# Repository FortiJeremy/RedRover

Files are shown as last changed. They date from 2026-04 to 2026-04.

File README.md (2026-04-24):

# RedRover

A Curiosity/Perseverance-inspired rover built on the [Mars-Rover](https://github.com/jakkra/Mars-Rover)
mechanical and ESP32 firmware platform, extended with:

- **ArduRover** autopilot (Pixhawk / Matek / CubePilot) for full autonomous navigation
- **GPS + compass** for waypoint missions, RTL, and geo-fencing
- **LiDAR** (RPLidar A1 / TFMini-Plus) for proximity-based collision avoidance
- **SiK telemetry** radio link to Mission Planner / QGroundControl
- Refactored ESP32 firmware bridging MAVLink for arm, head, and auxiliary servo control

## Repo structure

```
RedRover/
  Mars-Rover/           ← git submodule — fork of jakkra/Mars-Rover (ESP32 firmware + CAD)
  3d-prints/            ← STL files exported from the Fusion 360 full assembly
    _context_only/      ← reference-only meshes (bearings, servos, motors, fasteners) — DO NOT PRINT
    01_chassis_body/    ← outer hull panels + electronics bay lid
    02_head_pack1/      ← head rotator, housing, camera mount, servo horns
    03_head_pack2/      ← large head top connector parts
    04_arm_structure/   ← arm links 1–3 and body connectors
    05_arm_gripper_connector/  ← gripper connector, rotator, printed servo horns
    06_gripper_fingers/ ← gear horns, finger arms, plates, rods
    07_suspension_connectors/  ← rocker-bogie pivot connectors (left + right)
    08_wheel_hub_smalls/ ← hub faces, axle flanges, steering knuckle small bodies
    09_wheel_corner_A/  ← corner wheel outer shell (×4)
    10_wheel_corner_B/  ← corner wheel inner shell / TPU candidate (×4)
    11_wheel_middle_A/  ← middle wheel outer skin / TPU candidate (×2)
    12_wheel_middle_B/  ← middle wheel inner body (×2)
    13_core_structure_A/ ← rover core body parts — large singles
    14_core_structure_B/ ← rover core body parts — batch B
    15_core_structure_C/ ← rover core body parts — batch C
    16_core_structure_D/ ← rover core body parts — batch D
    17_core_structure_E/ ← rover core body parts — batch E (includes Body46 ⚠️ verify before printing)
  ardurover/
    params/             ← ArduRover .param files
    docs/               ← calibration and setup guides
  docs/
    10_bom.md              ← full bill of materials (original + RedRover additions)
    20_print-settings.md   ← slicer settings and material guide per pack
    30_assembly.md         ← chapter-by-chapter assembly guide
    40_wiring.md           ← pin assignments, servo channel map, power rail overview
    50_ardurover-setup.md  ← ArduRover parameter setup, calibration, LiDAR, geofence
    60_gcs-setup.md        ← Mission Planner / QGC connection and field checklist
    70_firmware-esp32.md   ← ESP32 firmware architecture and MAVLink refactor plan
  TODO.md
  README.md
```

### 3D prints overview

295 STL files were exported from the Fusion 360 assembly. **156 files** are purchased-part
reference geometry (Ball Bearing 608ZZ, SKF 6005, Servo MG996R bodies, DC motors, McMaster
fasteners, Pololu hub) — these live in `_context_only/` and should **never** be sliced.
The remaining **139 files** are printable parts, organized into 17 build packs each under 10 MB
raw (slicer project files add overhead on top of the STL sizes).

> **Note on servo horns:** the `servo_and_horn v2 (N)_1_Body1.stl` files are the 3D-printed
> servo horns — they are in the build packs, not `_context_only/`, even though their sibling
> `Servo MG996R v2_*_Body*.stl` files are context-only.

See [TODO.md — Priority 5](TODO.md) for the full step-by-step organization plan and remaining tasks.

## Getting started

Clone with submodules:

```bash
git clone --recurse-submodules git@github.com:FortiJeremy/RedRover.git
```

If you already cloned without `--recurse-submodules`:

```bash
git submodule update --init --recursive
```

## Related repos

| Repo | Purpose |
|---|---|
| [FortiJeremy/Mars-Rover](https://github.com/FortiJeremy/Mars-Rover) | ESP32 peripheral firmware + Fusion 360 CAD (submodule) |
| [jakkra/Mars-Rover](https://github.com/jakkra/Mars-Rover) | Upstream source |
| [jakkra/RoverController](https://github.com/jakkra/RoverController) | Original handheld controller |

## Build status

Early build phase — see [TODO.md](TODO.md) for full scope.

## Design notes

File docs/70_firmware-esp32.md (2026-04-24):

# ESP32 Firmware

The ESP32 firmware lives in `Mars-Rover/src/` and is built with PlatformIO
targeting the **TTGO LoRa32 v1** (Espressif ESP32, Arduino framework).

---

## Current Architecture (upstream Mars-Rover)

The firmware runs on a single ESP32 and is the sole controller for the entire rover.
It handles RC input, WiFi/LoRa control, motor driving, servo control, IMU, and telemetry.

### Module overview

| File | Responsibility |
|---|---|
| `main.cpp` | Setup, main loop, mode switching, controller arbitration |
| `rover_config.h` | All pin assignments, RC ranges, servo trim offsets, constants |
| `rover_driving.cpp/.h` | ESC PWM output (left/right), steering servo, drive modes |
| `rover_servo.cpp/.h` | PCA9685 I2C servo driver — all 13 servo channels |
| `arm.cpp/.h` | 6-DOF arm axis movement with speed ramping (uses `Ramp` library) |
| `rover_head.cpp/.h` | Head yaw/pitch servo control |
| `rc_receiver_rmt.cpp/.h` | 6-channel RC PWM input via ESP32 RMT peripheral |
| `wifi_controller.cpp/.h` | Async WebSocket server + UDP; AP or STA mode |
| `lora_controller.cpp/.h` | LoRa radio TX/RX via arduino-LoRa library |
| `gyro_accel_sensor.cpp/.h` | MPU-6050 I2C IMU — reads accel/gyro/angle, runs in FreeRTOS task |
| `rover_settings_switch.cpp/.h` | Reads 2-position GPIO switches at boot to select startup mode |
| `switch_checker.cpp/.h` | RoverMode / ArmMode enum and debounce logic |
| `data/index.html` | Web UI (virtual joystick) — uploaded to SPIFFS via `pio run -t uploadfs` |
| `data/virtualjoystick.js` | Joystick library for web UI |

### Control arbitration

Three input sources compete for control. Priority order (highest wins):
1. **WiFi WebSocket** — overrides RC and LoRa when a client connects
2. **LoRa** — overrides RC when LoRa packets received and WiFi not connected
3. **RC receiver** — default fallback

### Drive modes (RoverMode)

Controlled by RC CH5 switch position:
- `DRIVE_TURN_NORMAL` — both ESCs same signal; corner servos steer normally
- `DRIVE_TURN_SPIN` — left/right ESCs run opposite directions for pivot turn

### Arm modes (ArmMode)

Controlled by RC CH6 switch position:
- `ARM_MODE_MOVE` — joysticks drive arm axes 1–4 (CH1–CH4)
- `ARM_MODE_MOVE_GRIPPER` — joysticks drive axes 5–6 (gripper)
- Direct axis control — no IK. **IK is listed as TODO in the original codebase.**

### Key constants (rover_config.h)

```c
RC_LOW    = 1000   // µs
RC_CENTER = 1500   // µs
RC_HIGH   = 2000   // µs
RC_FILTER_SAMPLES = 2          // sliding average filter window

SERVOMIN      = 250            // PCA9685 counts (normal range)
SERVOMAX      = 500
SERVOMIN_FULL_RANGE = 150      // extended range
SERVOMAX_FULL_RANGE = 600

SERVO_FRONT_LEFT_OFFSET  = +20
SERVO_FRONT_RIGHT_OFFSET = -15
SERVO_BACK_LEFT_OFFSET   = +5
SERVO_BACK_RIGHT_OFFSET  = -25
```

### Libraries (platformio.ini)

```ini
lib_deps =
    ESP32Servo           ; ESC and direct servo PWM
    Ramp                 ; Smooth servo speed ramping in arm.cpp
    MPU6050_tockn        ; MPU-6050 IMU driver
    Adafruit PWM Servo Driver Library  ; PCA9685 I2C servo expander
    AsyncTCP             ; Required by ESP Async WebServer
    ESP Async WebServer  ; WebSocket + HTTP server for web UI
    arduino-LoRa (sandeepmistry)  ; LoRa radio
```

---

## RedRover Refactor Plan

The ESP32 is demoted from sole controller to peripheral/companion.
ArduRover FC handles all motor/ESC control and navigation; ESP32 manages
servos (arm, head, steering) and acts as a MAVLink bridge.

### Changes required

#### 1. Remove direct ESC control
- `rover_driving.cpp`: disable/stub out `motors_left` and `motors_right` ESC PWM output
- GPIO 17 and 13 no longer used for ESC signal
- `rover_driving_move()` to be replaced with MAVLink RC override or removed entirely

#### 2. Remove direct RC receiver input for motion
- RC receiver SBUS/PPM physically rewired to FC RC IN port
- The 6 RC GPIO inputs (34, 35, 4, 39, 25, 36) may be repurposed or left as monitoring-only
- Arm and head RC channels can still be read locally on ESP32, or forwarded via MAVLink

#### 3. Add MAVLink serial link to FC
- New UART on ESP32 (e.g. `Serial2`) connected to FC TELEM2 port
- Add `mavlink` library to `platformio.ini`
- Implement heartbeat TX (Type: `MAV_TYPE_ONBOARD_CONTROLLER`)
- Parse incoming heartbeat + `RC_CHANNELS_OVERRIDE` from FC

#### 4. Retain servo control
- PCA9685 I2C bus and all 13 servo channels remain on ESP32
- `rover_servo.cpp` unchanged — still drives arm (axes 1–6), steering (4 corners), head (yaw + pitch)
- Arm mode / head control still driven by WiFi WebSocket or LoRa

#### 5. Telemetry bridge (optional)
- ESP32 reads MAVLink telemetry from FC (battery, GPS, mode, heading)
- Forwards over WebSocket to browser or custom GCS web UI
- Existing `wifi_controller.cpp` WebSocket infrastructure can be reused

#### 6. Arm IK (future)
- `arm.cpp` currently maps RC channels 1:1 to axis µs positions
- Plan: implement FABRIK or analytical 6-DOF IK
- IK target (x,y,z + euler) accepted via WebSocket JSON message or MAVLink custom message
- `arm_move()` already has speed parameter — reuse for IK interpolation

---

## Build & Flash

```bash
# Build
pio run

# Flash
pio run -t upload

# Monitor serial
pio device monitor

# Upload web UI to SPIFFS
pio run -t uploadfs

# Decode crash stack trace
xtensa-esp32-elf/bin/xtensa-esp32-elf-addr2line.exe -pfiaC -e .pio/build/esp-wrover-kit/firmware.elf 0x...
```

Default port: `COM8` at 921600 baud upload / 115200 baud monitor (set in `platformio.ini`).
Update `upload_port` / `monitor_port` in `platformio.ini` if your port differs.

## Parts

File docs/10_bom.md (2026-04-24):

# Bill of Materials

---

## Original Mars-Rover Hardware

These are the parts from the upstream jakkra/Mars-Rover design.
Quantities are for the full rover with arm and head.

### Drive System

| Part | Qty | Notes |
|---|---|---|
| 12V 60RPM DC motor | 6 | One per wheel — see [issue #6](https://github.com/jakkra/Mars-Rover/issues/6) for specific model |
| Brushless ESC | 2 | One per side (each drives 3 motors in parallel) |
| Pololu 4mm shaft hub (M3 holes) | 6 | [Pololu #1081](https://www.pololu.com/product/1081) — motor-to-wheel adapter |

### Steering & Servos

| Part | Qty | Notes |
|---|---|---|
| MG946R or MG996R servo | 4 | Corner wheel steering |
| MG946R servo | 6 | 6-DOF arm axes |
| MG946R or MG996R servo | 2 | Head yaw + pitch |
| Round Metal Servo Horn 25T Disc | 12 | One per servo — check spline compatibility |

### Power

| Part | Qty | Notes |
|---|---|---|
| 3S LiPo battery | 1 | Capacity TBD based on runtime target — suggest 5000–6000 mAh |
| 12V → 5V switching voltage regulator | 12 | One per servo — can be replaced with high-current BECs (see RedRover additions) |

### Compute & Control

| Part | Qty | Notes |
|---|---|---|
| TTGO LoRa32 v1 (ESP32) | 1 | Main MCU — board used in platformio.ini |
| Adafruit PCA9685 PWM servo driver | 1 | I2C servo expander — drives all 13 servos on channels 0–12 |
| MPU-6050 IMU (gyro/accel) | 1 | On I2C bus with PCA9685 |
| 6-channel RC receiver | 1 | Generic PPM/PWM receiver |
| LoRa radio module | 1 | Built into TTGO LoRa32 (SX1276 or SX1278) |

### Structural

| Part | Qty | Notes |
|---|---|---|
| PVC pipe, ID 23.40 mm / OD 25 mm | TBD | Rocker-bogie arms — measure from CAD |
| Ball bearing 608ZZ | 5+ | Check CAD for exact count per side |
| Bearing SKF 6005 (25 mm) | 5+ | Larger wheel pivot bearings — check CAD |
| M3 screws assorted | ~100 | Primary fastener throughout |
| M4 screws assorted | ~20 | Larger structural joints |
| M3 heat-set inserts | ~50 | For 3D-printed holes — strongly recommended over direct screw-in |

---

## RedRover Additions (ArduRover / GPS / LiDAR build)

### Autopilot

| Part | Qty | Notes |
|---|---|---|
| ArduRover-compatible flight controller | 1 | **Recommended:** Pixhawk 6C, Matek H743-Wing, or CubePilot Orange+ |
| Vibration isolation foam / mounting kit | 1 | Required under FC — standard FC mounting foam |

### Navigation

| Part | Qty | Notes |
|---|---|---|
| u-blox M8N or M9N GPS + compass module | 1 | **Recommended:** Here3 or mRo GPS — integrated compass |
| GPS mast (printed or purchased) | 1 | Elevates GPS above chassis electronics noise |

### Collision Avoidance

| Part | Qty | Notes |
|---|---|---|
| RPLidar A1M8 (360° 2D LiDAR) | 1 | **Recommended** — full perimeter coverage, ~$100, supported natively by ArduRover `PRX_TYPE=5` |
| *OR* TFMini-Plus (single-point ToF) | 1 | Budget alternative — forward-only, `RNGFND1_TYPE=20` |

### Telemetry

| Part | Qty | Notes |
|---|---|---|
| SiK 915 MHz radio pair | 1 pair | e.g. RFD900x or HolyBro SiK v3 — one on rover, one to GCS |

### Power

| Part | Qty | Notes |
|---|---|---|
| ArduRover power module | 1 | e.g. **Matek HUBOSD** or Holybro PM02 — provides VBAT + current sense to FC ADC |
| 5A BEC (12V → 5V) | 2–3 | e.g. Matek MBEC6S — replaces 12× individual regulators. One per servo rail zone |
| Power distribution board (PDB) | 1 | Routes 12V from battery to ESCs, BECs, FC, LiDAR |
| 30–40A blade fuse + holder | 1 | Main fuse between battery and PDB |
| XT60 connector pair | 2–3 | Battery and PDB connections |

### Safety

| Part | Qty | Notes |
|---|---|---|
| ArduRover safety arming button | 1 | Wired to FC safety switch port — required for arming |

---

## Connectors & Wiring Hardware

| Part | Notes |
|---|---|
| JST connectors assorted | ESC signal, servo extensions |
| Dupont 2.54mm header kit | ESP32 and FC GPIO breakouts |
| Heat-shrink tubing assorted | |
| Cable ties / wire loom | |
| XT30 or XT60 pigtails | ESC power inputs |

---

## Still TBD

- [ ] Exact DC motor model/SKU — see Mars-Rover issue #6
- [ ] Cable loom lengths — measure from CAD / physical assembly
- [ ] ESC model selection — confirm PWM range compatible with ArduRover output
- [ ] 3S LiPo C-rating and capacity — size to current budget once calculated
- [ ] Heat-set insert sizes per part — note during assembly

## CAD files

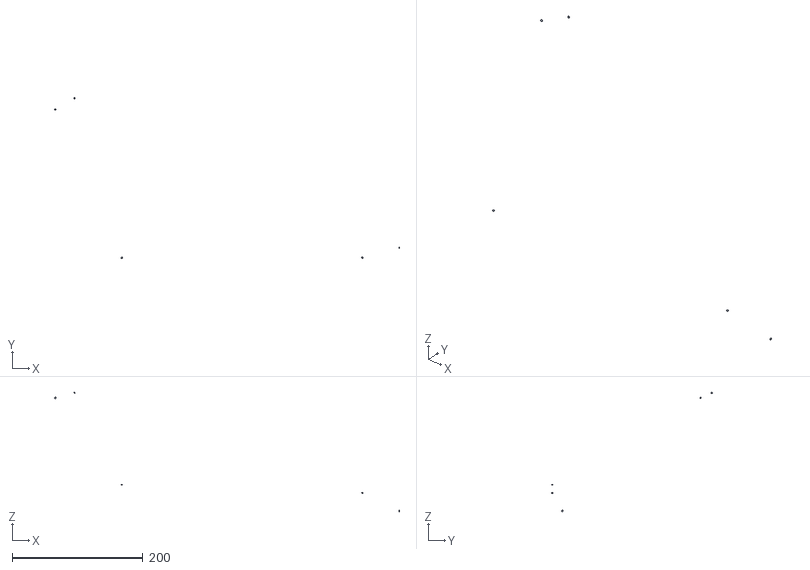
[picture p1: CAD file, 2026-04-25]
3d-prints/_context_only/Rover_Full_Rover_Full_Rover body_1_Rover core and arm v81_1_arm_gripper_connector_1_servo_and_horn v2 (2)_1_Servo MG996R v2_3_Body4.stl
528.2 x 247.0 x 183.1

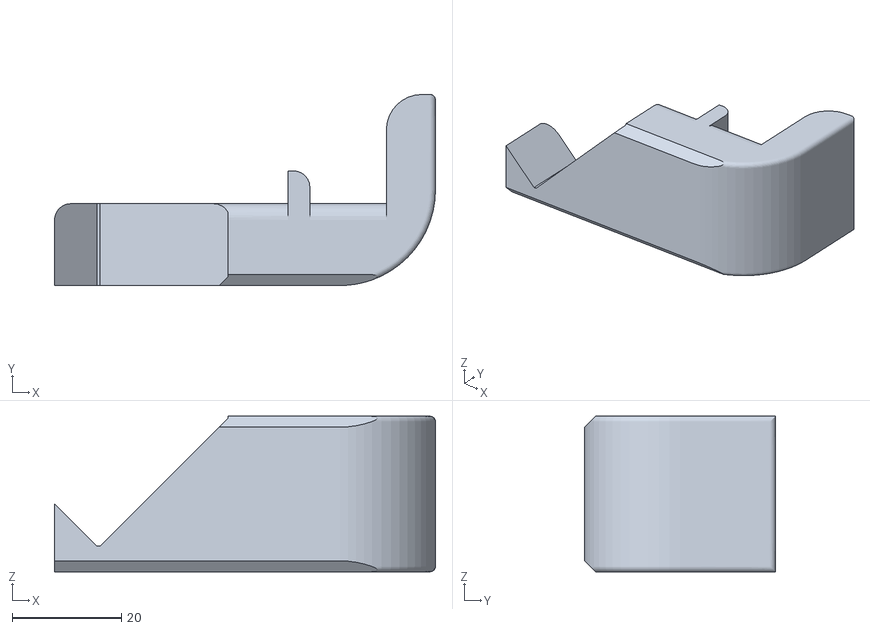
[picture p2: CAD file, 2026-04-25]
3d-prints/arm_objects/Rover_Full_Rover_Full_arm_holder_1_Body1.stl
69.8 x 35.0 x 28.5

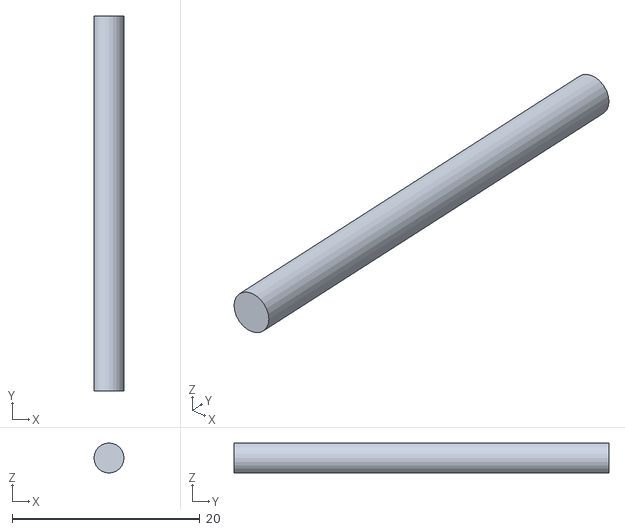
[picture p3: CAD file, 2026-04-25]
3d-prints/back_antennae/Rover_Full_Rover_Full_ruhf_antenna_1_Body6.stl
3.20 x 40.0 x 3.20

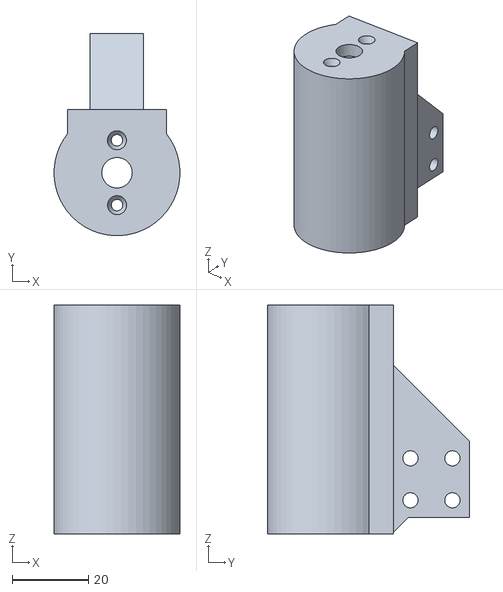
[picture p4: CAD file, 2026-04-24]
3d-prints/Body/1-middle-wheels/Rover_Full_Rover_Full_Rover body_1_Rover core and arm v81_1_Rover core v232_1_middle_wheel_1_Body1.stl
32.9 x 53.0 x 60.0

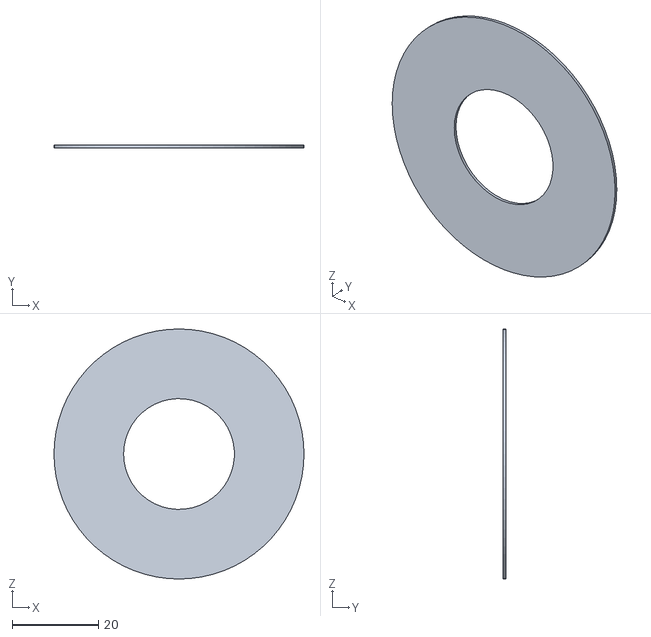
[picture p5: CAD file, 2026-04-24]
3d-prints/Body/1-port-driveline/Rover_Full_Rover_Full_Rover body_1_Rover core and arm v81_1_Rover core v232_1_Body35.stl
58.0 x 0.6 x 58.0

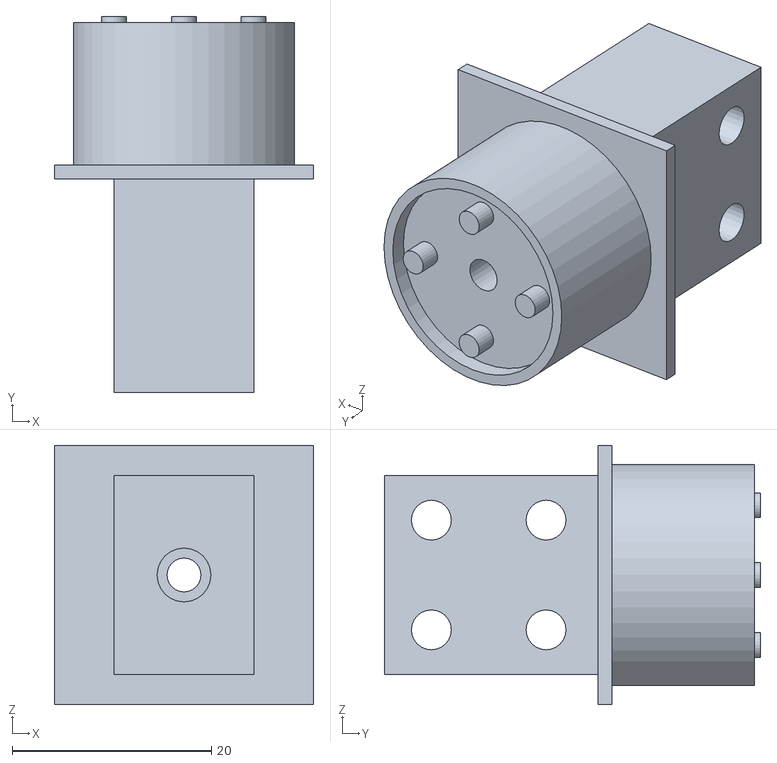
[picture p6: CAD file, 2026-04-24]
3d-prints/Body/1-starboard-driveline/Rover_Full_Rover_Full_Rover body_1_Rover core and arm v81_1_Rover core v232_1_Body1.stl
26.0 x 37.7 x 26.0

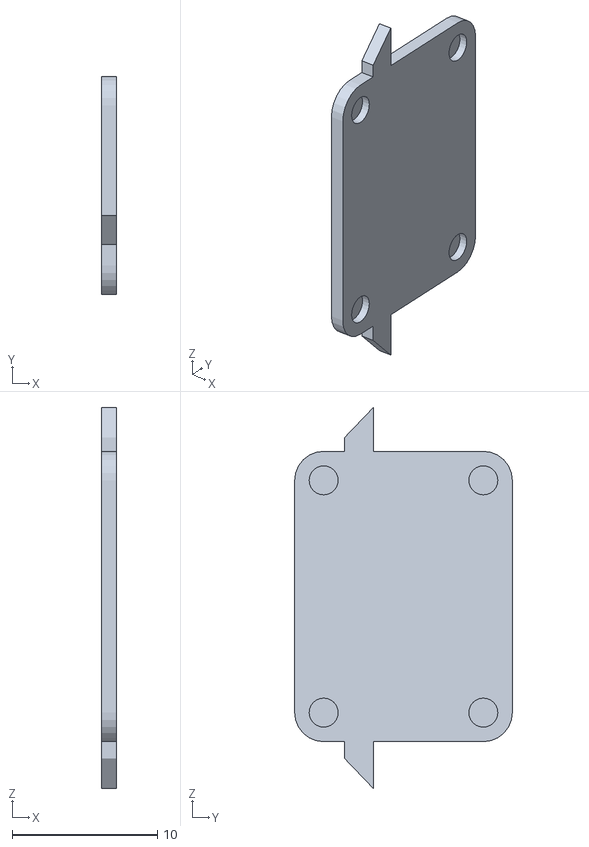
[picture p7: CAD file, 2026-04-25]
3d-prints/Body/main-box/_context_only/Rover_Full_Rover_Full_Rover body_1_Body9.stl
1.00 x 15.0 x 26.2

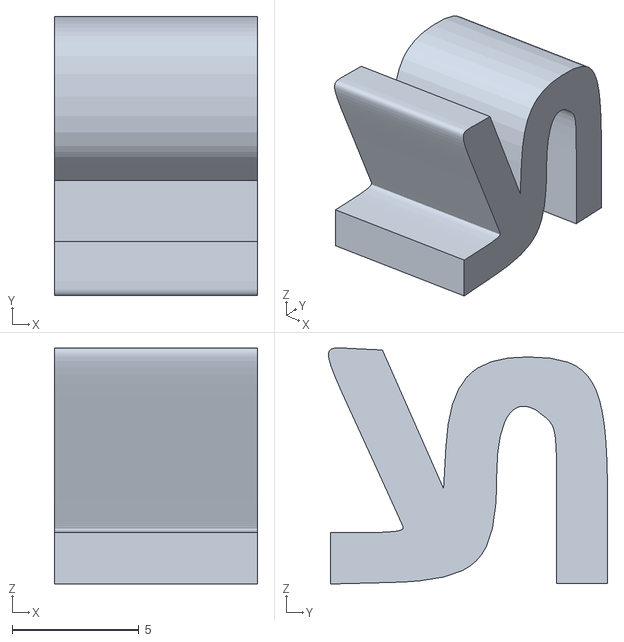
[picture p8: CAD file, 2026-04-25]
3d-prints/Body/main-box/Krantz-Logo-Back/Rover_Full_Rover_Full_Rover body_1_Rover core and arm v81_1_Rover core v232_1_Body48.stl
8.00 x 11.0 x 9.30

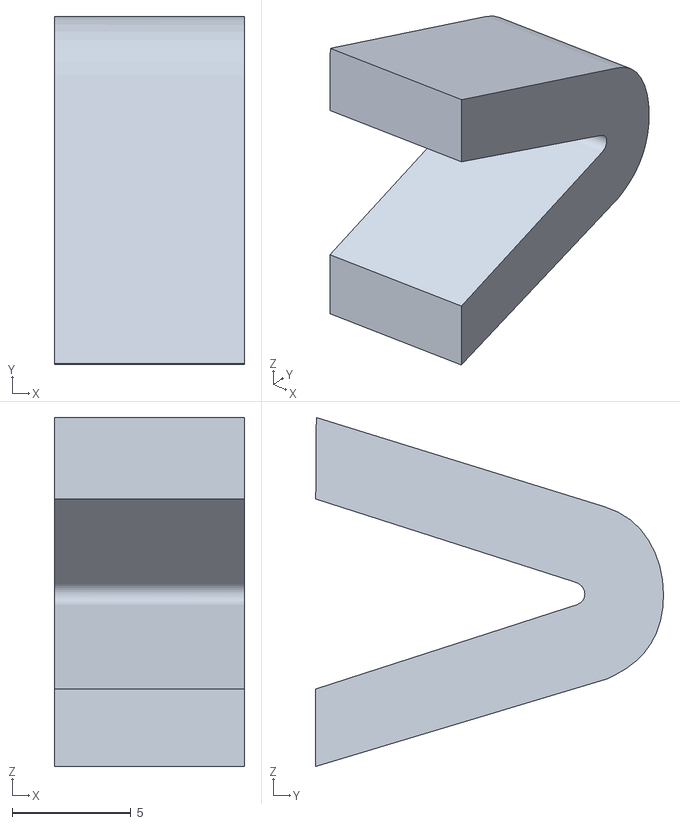
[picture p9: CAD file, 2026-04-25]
3d-prints/Body/main-box/NASA-Logo-Front/Rover_Full_Rover_Full_Rover body_1_Rover core and arm v81_1_Rover core v232_1_Body43.stl
8.00 x 14.6 x 14.7

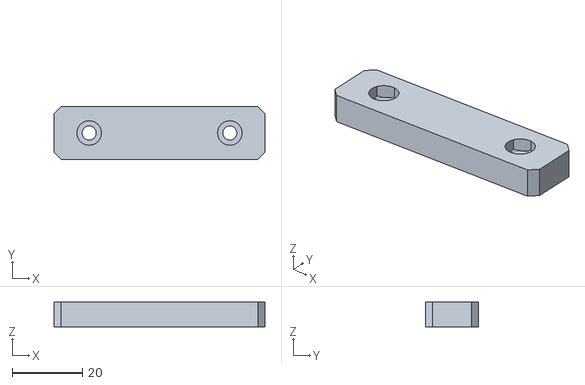
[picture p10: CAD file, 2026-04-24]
3d-prints/Body/main-box/Rover_Full_Rover_Full_Rover body_1_Rover core and arm v81_1_Rover core v232_1_Body40.stl
60.0 x 15.0 x 7.00

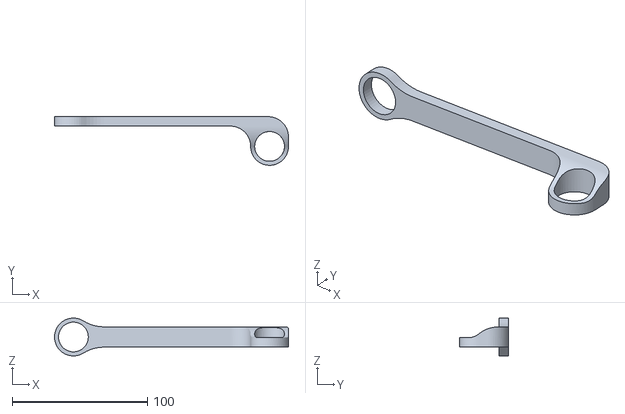
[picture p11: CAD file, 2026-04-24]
3d-prints/Body/sway-link/Rover_Full_Rover_Full_Rover body_1_Rover core and arm v81_1_Rover core v232_1_Body22.stl
173.0 x 36.0 x 28.0

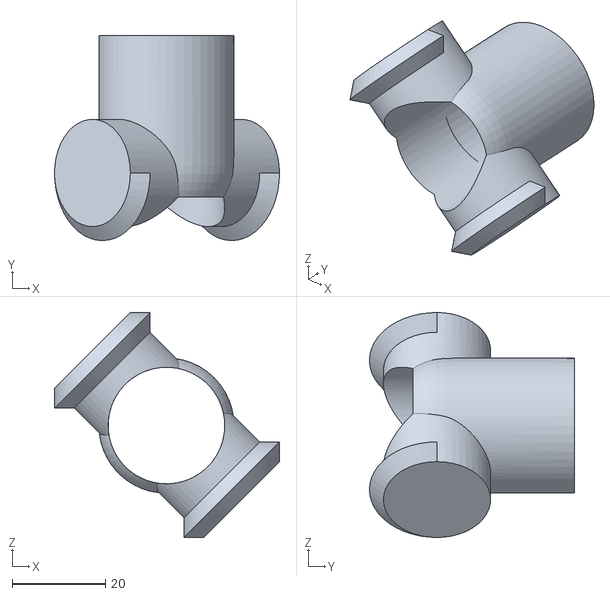
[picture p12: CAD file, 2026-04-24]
3d-prints/camera/Rover_Full_Rover_Full_Rover body_1_head_top_connector_1_Body3.stl
48.2 x 44.0 x 48.2

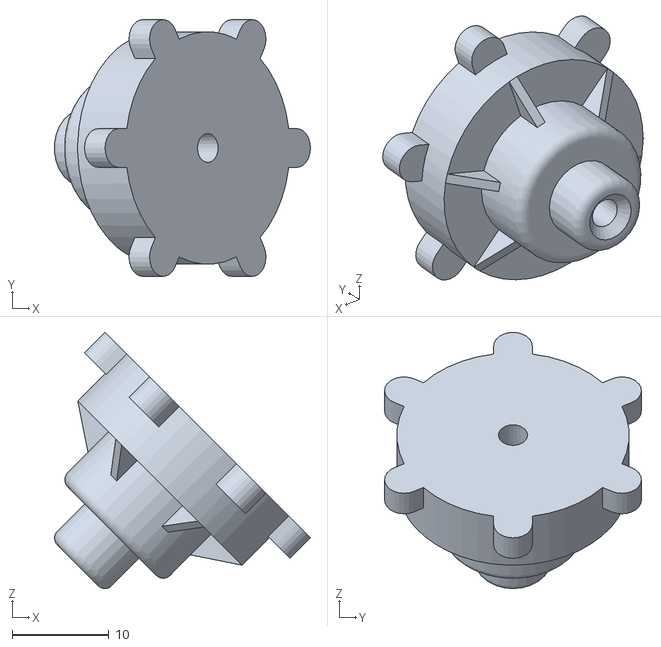
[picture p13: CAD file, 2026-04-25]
3d-prints/large_antenna/Rover_Full_Rover_Full_large_antenna_1_Body17.stl
26.4 x 26.5 x 26.5

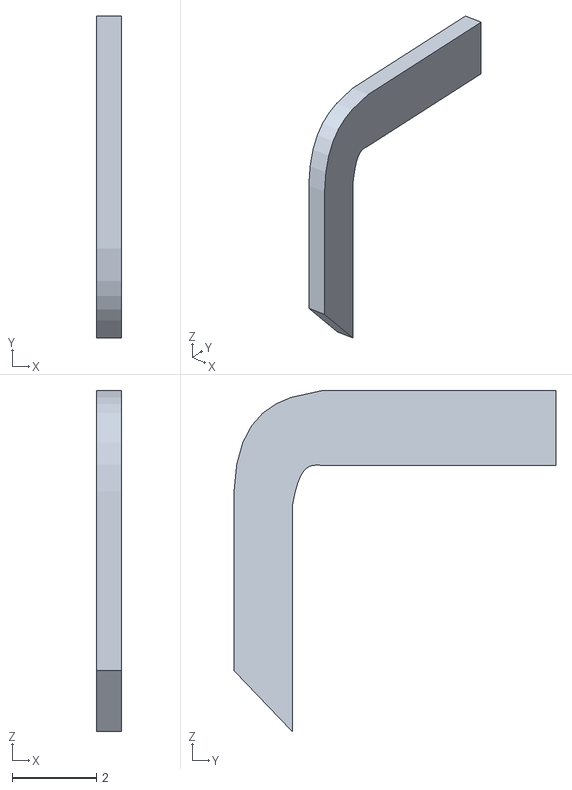
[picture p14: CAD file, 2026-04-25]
3d-prints/Reactor_and_addons/Rover_Full_Rover_Full_Body5.stl
0.6 x 7.64 x 8.11

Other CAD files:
3d-prints/Body/1-rear-corner-wheels/Rover_Full_Rover_Full_Rover body_1_Rover core and arm v81_1_Rover core v232_1_corner_wheel2_1_Body3.stl
3d-prints/Top_Thingies/Rover_Full_Rover_Full_top_thingy(Mirror)_1_Body2.stl
3d-prints/3mf-files/MainBox.3mf
3d-prints/_context_only/Rover_Full_Rover_Full_large_antenna_1_servo_and_horn v2 (1) (1)_1_Servo MG996R v2 (1)_1_Body3.stl
3d-prints/3mf-files/Lids&Side.3mf
3d-prints/Body/1-middle-wheels/Rover_Full_Rover_Full_Rover body_1_Rover core and arm v81_1_Rover core v232_1_middle_wheel_1_Body2.stl
3d-prints/Body/1-middle-wheels/Rover_Full_Rover_Full_Rover body_1_Rover core and arm v81_1_Rover core v232_1_middle_wheel_1_Body5.stl
3d-prints/Body/1-port-driveline/Rover_Full_Rover_Full_Rover body_1_Rover core and arm v81_1_Rover core v232_1_Body27.stl
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

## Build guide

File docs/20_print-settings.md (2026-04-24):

# 3D Print Settings

Reference slicer settings and material recommendations for all RedRover printed parts.
Print packs are in `3d-prints/` — see the [repo README](../README.md) for the full pack list.

---

## Material Guide by Sub-Assembly

| Pack | Sub-assembly | Recommended material | Rationale |
|---|---|---|---|
| 01 | Chassis body panels | PETG or PLA+ | Light structural load, cosmetic accuracy matters |
| 02–03 | Head assembly | PLA+ | Low stress, dimensional accuracy for servo fits |
| 04–05 | Arm structure + gripper connector | PETG | Repeated torsional loads on arm links |
| 06 | Gripper fingers / gear horns | PETG | Wear surface on gear teeth |
| 07 | Suspension connectors (rocker-bogie) | PETG or ASA | High stress pivot joints — do NOT use PLA |
| 08 | Wheel hub small parts | PETG | Axle loads |
| 09, 11 | Wheel outer skins | **TPU 95A** (flex) or PETG (rigid) | TPU gives Mars 2020-style grip on outdoor terrain |
| 10, 12 | Wheel inner shells | PETG | Structural backbone of wheel |
| 13–17 | Rover core structure | PETG | Frame members carry most structural load |

---

## General Slicer Settings (starting point — tune per printer)

| Parameter | Value | Notes |
|---|---|---|
| Layer height | 0.2 mm | 0.15 mm for servo horn mating surfaces |
| Line width | 0.4 mm (nozzle) | |
| Infill — structural parts | 40% gyroid | Rocker-bogie pivots, arm links, wheel hubs |
| Infill — cosmetic/light parts | 20% gyroid | Panels, head housing |
| Perimeters / walls | 4 | Minimum for all structural parts |
| Top/bottom layers | 5 | |
| Print speed | 50 mm/s | Slow to 30 mm/s for first layer and bridges |
| Supports | See per-pack notes | Use tree/organic supports where possible |
| Bed adhesion | Brim 5 mm | For tall narrow parts; raft for TPU |

---

## TPU-Specific Settings (wheel outer skins — packs 09 & 11)

| Parameter | Value |
|---|---|
| Print speed | 20–25 mm/s |
| Retraction | Disabled or ≤0.5 mm (direct drive) / Off (Bowden) |
| Temperature | ~230°C nozzle, ~45°C bed |
| Cooling fan | 100% after layer 3 |
| Infill | 15% gyroid — gives flex behaviour |
| Walls | 3 |
| Bed adhesion | PEI sheet or glue stick on glass |

---

## Pack-Specific Notes

### Pack 07 — Suspension Connectors
- `main_leg_body_connector` and its mirror are the single highest-stress printed parts.
  Orient so layer lines run along the length of the arm (perpendicular to the load).
- If using PETG, anneal in oven at 65°C for 2 hrs after printing for improved creep resistance.

### Pack 09 / 10 — Corner Wheels (×4 each)
- Body1 (~4 MB) is a large print — validate fit with a single copy before queuing all 4.
- Print corner wheel outer and inner as separate jobs; glue or snap together after.
- Wheel outer needs 4 copies; mirror is handled in hardware (symmetric wheel), not by mirroring the STL.

### Pack 11 / 12 — Middle Wheels (×2 each)
- Same approach as corner wheels — validate one before printing the second.

### Pack 13 — Core Structure Large Bodies
- Body6 and Body33 are each ~4 MB — likely main chassis frame rails. Verify print bed fits.
- Best orientation: flat face down, no supports on inner channels if hollowed.

### Pack 17 — Body46 ⚠️
- Body46 is 7.3 KB — very small mesh. Open in CAD before printing; may be a hardware reference
  that was not caught in the context-only pass.

---

## Print Order Recommendation

Print in this dependency order so you can begin dry-fitting before all parts are done:

1. Packs 13–17 (core structure) — longest print time, needed first for chassis assembly
2. Pack 07 (suspension connectors)
3. Pack 08 + 09 + 10 (wheel hubs + corner wheel shells) × 4
4. Pack 11 + 12 (middle wheel shells) × 2
5. Pack 01 (chassis body panels)
6. Pack 04 + 05 + 06 (arm structure + gripper)
7. Packs 02 + 03 (head)

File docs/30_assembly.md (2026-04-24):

# Assembly Guide

High-level chapter guide for building the RedRover. Each section corresponds to a
physical sub-assembly. Follow the order below — each stage should be testable on its own
before moving to the next.

> **Reference:** Keep the Fusion 360 model open (`Mars-Rover/CAD/Rover_Full.f3d`) throughout.
> The CAD is the source of truth for all dimensions, orientations, and fit.

---

## Chapter 1 — Tools & Prep

**Required tools:**
- M3 and M4 hex keys (ball-end preferred)
- M3 / M4 screwdriver bits
- Soldering iron with fine tip
- Heat-set insert tip for soldering iron (M3 preferred)
- Needle-nose pliers
- Bearing press tool (or M3 bolt + nut + socket as improvised press)
- Digital calipers
- Hot glue gun (cable management / light tacks only — no structural glue)

**Before starting:**
- [ ] Install all heat-set inserts into printed parts before assembly — much easier to do on the bench
- [ ] Test-fit all bearings dry before pressing — 608ZZ into wheel hubs, SKF 6005 into pivot journals
- [ ] Ream any tight bearing seats with a hobby knife or light sandpaper — do not force-press into undersized holes
- [ ] Sand/file any layer lines on servo mounting faces to ensure servo horns seat flush

---

## Chapter 2 — Rocker-Bogie Suspension

The rocker-bogie is the structural spine of the rover. Six wheels are driven by a passive
differential linkage; the front and rear corners steer independently.

**Main printed parts (from print packs 07, 13–17):**
- 2× `main_leg_body_connector` (left + right)
- 2× `back_two_wheel_connector` (left + right)
- Rover core frame bodies from packs 13–17

**Purchased hardware:**
- PVC pipe (ID 23.40 mm / OD 25 mm) — cut to lengths from CAD
- SKF 6005 25 mm bearings (pivot journals)
- 608ZZ bearings (wheel axles)
- M3 / M4 fasteners and heat-set inserts

**Assembly steps (TBD — cross-reference CAD):**
- [ ] Assemble left and right bogie links with PVC pipe inserts
- [ ] Press SKF 6005 bearings into pivot housings (main_leg_body_connector)
- [ ] Connect rocker to bogie via pivot pin — confirm free rotation, no binding
- [ ] Attach bogie sub-assemblies to core frame rails
- [ ] Install differential rocker bar between left and right bogies

**Alignment check:**
- With rover on a flat surface, all 6 wheel contact points should touch simultaneously
- Rocker pivot should float freely — it should not be fastened rigidly

---

## Chapter 3 — Drive Train

Each of the 6 wheels is independently driven by a 12V 60RPM DC motor.
Motors on the left 3 wheels share one ESC; right 3 wheels share the second ESC.

**Main printed parts (from packs 08, 09, 10, 11, 12):**
- 4× corner wheel assembly (outer + inner shell, hub small parts)
- 2× middle wheel assembly (outer + inner shell)

**Purchased hardware:**
- 6× DC motor
- 6× Pololu #1081 shaft hub
- 608ZZ bearings
- M3 fasteners

**Assembly steps (TBD):**
- [ ] Mount each DC motor into its wheel housing
- [ ] Press Pololu shaft hubs onto motor 4mm output shaft — secure M3 grub screws with Loctite
- [ ] Press 608ZZ bearings into outer wheel shells
- [ ] Assemble wheel outer shell onto hub — verify correct side (asymmetric for cornering)
- [ ] Mount wheel assemblies to bogie arms — check for wheel toe/camber

**Corner wheel note:**
Corner wheels carry a steering servo in addition to the drive motor. See Chapter 4 for
steering servo installation before finalising corner wheel assembly.

---

## Chapter 4 — Steering Servos (Corner Wheels)

Four MG946R/MG996R servos steer the front-left, front-right, back-left, and back-right wheels.
Servos are installed inside the corner wheel assembly and driven via the PCA9685 expander.

**PCA9685 servo channels (from `rover_servo.h`):**
| Channel | Servo |
|---|---|
| 6 | `SERVO_FRONT_RIGHT` |
| 7 | `SERVO_BACK_LEFT` |
| 8 | `SERVO_FRONT_LEFT` |
| 9 | `SERVO_BACK_RIGHT` |

**Trim offsets (from `rover_config.h`):**
| Servo | Offset |
|---|---|
| Front Left | +20 µs |
| Front Right | −15 µs |
| Back Left | +5 µs |
| Back Right | −25 µs |

**Assembly steps (TBD):**
- [ ] Install servo into corner wheel housing — align spline notch before inserting
- [ ] Attach 25T disc horn — set to mechanical centre first using servo tester or firmware
- [ ] Verify wheel points straight ahead at 1500 µs centre signal
- [ ] Fine-tune offsets in `rover_config.h` if required

---

## Chapter 5 — 6-DOF Arm

The arm has 6 servo-driven joints (MG946R). Currently the arm is directly RC-mapped;
inverse kinematics is planned for a future firmware update.

**Main printed parts (from packs 04, 05, 06):**
- arm link 1 (`arm_1_1_Body1`)
- arm body connector (`arm_body_connector_1_Body1`)
- arm links 2 + mirror (`arm2`, `arm2(Mirror)(Mirror)`)
- arm link 3 (`arm3_1_Body1`)
- gripper connector assembly (`arm_gripper_connector_1_Body1/2`)
- grip rotator (`grip_rotator_1_Body1`)
- gripper finger assembly (packs 06)
- 3× printed servo horns (`servo_and_horn v2 (1–3)_1_Body1`)

**PCA9685 servo channels (from `rover_servo.h`):**
| Channel | Servo |
|---|---|
| 0 | `SERVO_ARM_AXIS_1` |
| 1 | `SERVO_ARM_AXIS_2` |
| 2 | `SERVO_ARM_AXIS_3` |
| 3 | `SERVO_ARM_AXIS_4` |
| 4 | `SERVO_ARM_AXIS_5` |
| 5 | `SERVO_ARM_AXIS_6` |

**Assembly steps (TBD):**
- [ ] Install AXIS_1 servo at base rotation joint (arm_body_connector)
- [ ] Route wiring through hollow arm links before closing
- [ ] Assemble links 1 → 2 → 3 in order — test each joint range before proceeding
- [ ] Install gripper connector and grip rotator (AXIS_5)
- [ ] Install gripper servo at AXIS_6 — connect gear horns
- [ ] Balance arm weight at each joint; note if any joint stalls under static load

**Arm range of motion:**
SERVOMIN (250) to SERVOMAX (500) in PCA9685 counts (full range: 150–600).
Firmware clamps to reduced range by default to protect servo gears.

---

## Chapter 6 — Head

The head has yaw (left/right) and pitch (up/down) driven by two MG946R/MG996R servos.
An ESP32-CAM mounts in the head for the video feed.

**Main printed parts (from packs 02, 03):**
- head rotator body (`head_rotator_1_Body1/2/3`)
- head housing (`head_rotator_1_head_1_Body1/2/3/4`)
- head top connector assembly (`head_top_connector_1_Body*`)
- ESP32-CAM holder (`espcam_holder_1_Body1/2`)
- 2× printed servo horns (`servo_and_horn v2 (4)_1_Body1`, `v2 (5)_1_Body1`)

**PCA9685 servo channels (from `rover_servo.h`):**
| Channel | Servo |
|---|---|
| 11 | `SERVO_HEAD_YAW` |
| 12 | `SERVO_HEAD_PITCH` |

**RC channel mapping (from `rover_config.h`):**
- Head yaw: RC_CH3 (GPIO4)
- Head pitch: RC_CH4 (GPIO39)

**Assembly steps (TBD):**
- [ ] Install yaw servo into head_rotator bracket; attach printed horn
- [ ] Install pitch servo into head housing; attach printed horn
- [ ] Mount ESP32-CAM into espcam_holder — confirm camera faces forward
- [ ] Mount head sub-assembly onto top of rover body via head_top_connector
- [ ] Verify full yaw/pitch range without cable binding

**Sensor mast note (RedRover addition):**
If mounting RPLidar on the head/top deck rather than a separate mast, provision cable path
and mount clearance for the LiDAR sensor here.

---

## Chapter 7 — Electronics Bay

The electronics bay is inside the main chassis body, covered by the printed lid (`Lid1.stl`).

**Planned component layout (TBD — diagram needed):**
- ArduRover flight controller (centre, vibration-isolated)
- TTGO LoRa32 ESP32 board
- PCA9685 PWM servo driver (I2C to ESP32)
- Power module (battery-side of PDB)
- PDB / BEC modules
- SiK telemetry radio
- RC receiver
- Safety arming button (mounted through lid or body panel)

**Assembly steps (TBD):**
- [ ] Mount PDB to bay floor — confirm cable routing to all 6 motors and servo BEC rails
- [ ] Mount power module in-line between XT60 battery connector and PDB
- [ ] Mount ArduRover FC on vibration foam — orient arrow forward
- [ ] Mount ESP32 (TTGO LoRa32) adjacent to FC — UART link between them
- [ ] Route all servo signal wires to PCA9685
- [ ] Route RC receiver to ESP32 GPIOs 34, 35, 4, 39, 25, 36 (CH1–CH6)
- [ ] Install safety button — wire to FC safety port
- [ ] Lid test fit — confirm no cables pinched

---

## Chapter 8 — First Power-On Checklist

Before first full power-on with all components connected:

- [ ] Verify polarity on all ESC power connections before plugging in
- [ ] Confirm all servo power rails are on regulated 5V, not direct battery
- [ ] Check for any short circuits across PDB rails with multimeter (no battery connected)
- [ ] Connect battery — check for smoke, heat, or excessive current draw before proceeding
- [ ] Verify FC boots and shows solid LED (no FC-specific error indications)
- [ ] Confirm ESP32 serial output on 115200 baud — check for crash/reboot loops
- [ ] Test each servo to centre before connecting to arm/steering linkages
- [ ] Test each motor direction — verify left/right ESC mapping matches firmware

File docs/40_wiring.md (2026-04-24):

# Wiring & Electrical

Wiring reference for the RedRover. The original Mars-Rover was a single-board ESP32 system;
the RedRover adds an ArduRover flight controller between the battery/ESCs and the ESP32,
which becomes a peripheral/companion board.

---

## System Architecture Overview

```
Battery (3S LiPo)
    │
    ├─ XT60 ──► Power Module ──► (VBAT + current sense to FC ADC)
    │                │
    │           PDB / Bus
    │           │          │          │          │
    │         ESC L       ESC R     BEC 1      BEC 2/3
    │       (Motors       (Motors   (5V servo  (5V for FC,
    │        L×3)          R×3)      rail)      ESP32, LiDAR)
    │
    └─ Fuse (30–40A blade)
```

---

## ESP32 (TTGO LoRa32 v1) Pin Assignment

From `src/rover_config.h`:

### RC Receiver Inputs (still wired direct to ESP32 in current firmware; to be rerouted to FC in RedRover)

| ESP32 GPIO | Signal | RC Channel |
|---|---|---|
| 34 | RC_CH1_INPUT | Steering |
| 35 | RC_CH2_INPUT | Throttle |
| 4 | RC_CH3_INPUT | Head Yaw |
| 39 | RC_CH4_INPUT | Head Pitch |
| 25 | RC_CH5_INPUT | Rover mode switch |
| 36 | RC_CH6_INPUT | Arm mode switch |

> **RedRover change:** RC receiver SBUS/PPM output will move to ArduRover FC RC IN port.
> ESP32 will receive RC channel values via MAVLink RC override messages from FC.

### Motor ESC Outputs (to be removed in RedRover — FC takes over)

| ESP32 GPIO | Signal |
|---|---|
| 17 | ESC left (3× motors) — PWM 1000–2000 µs |
| 13 | ESC right (3× motors) — PWM 1000–2000 µs |

> **RedRover change:** These pins will be disabled. ArduRover FC outputs drive both ESCs
> directly on its PWM output channels.

### I2C Bus

| ESP32 GPIO | Signal |
|---|---|
| 21 | SDA |
| 22 | SCL |

I2C devices on this bus:
- **PCA9685** PWM servo driver (13 servo channels — see servo channel table below)
- **MPU-6050** IMU (gyro/accel)

### Settings Switches (boot mode selection)

| ESP32 GPIO | Signal |
|---|---|
| 2 | ROVER_SETTINGS_SWITCH_1 |
| 23 | ROVER_SETTINGS_SWITCH_2 |

3-position switch combination controls startup mode:
- `ROVER_SWITCH_STATE_STATION_LORA` → WiFi station + LoRa enabled
- `ROVER_SWITCH_STATE_AP` → WiFi AP mode (hosted web UI)
- `ROVER_SWITCH_STATE_LORA_ONLY` → LoRa only, no WiFi

---

## PCA9685 Servo Driver Channel Map

All servos are driven through a single PCA9685 I2C PWM expander.
From `src/rover_servo.h`:

| PCA9685 Channel | RoverServoId | Connected servo |
|---|---|---|
| 0 | `SERVO_ARM_AXIS_1` | Arm base rotation |
| 1 | `SERVO_ARM_AXIS_2` | Arm shoulder |
| 2 | `SERVO_ARM_AXIS_3` | Arm elbow |
| 3 | `SERVO_ARM_AXIS_4` | Arm wrist pitch |
| 4 | `SERVO_ARM_AXIS_5` | Arm wrist roll |
| 5 | `SERVO_ARM_AXIS_6` | Gripper open/close |
| 6 | `SERVO_FRONT_RIGHT` | Front-right corner steering |
| 7 | `SERVO_BACK_LEFT` | Back-left corner steering |
| 8 | `SERVO_FRONT_LEFT` | Front-left corner steering |
| 9 | `SERVO_BACK_RIGHT` | Back-right corner steering |
| 10 | `SERVO_UNUSED` | Spare |
| 11 | `SERVO_HEAD_YAW` | Head left/right rotation |
| 12 | `SERVO_HEAD_PITCH` | Head up/down tilt |

**PWM range (from `rover_config.h`):**
- Default: SERVOMIN = 250, SERVOMAX = 500 (out of 4096)
- Full range: SERVOMIN_FULL_RANGE = 150, SERVOMAX_FULL_RANGE = 600
- Standard RC centre = 1500 µs

---

## ArduRover Flight Controller Wiring (RedRover additions)

### Serial / UART Connections

| FC Port | Connected to | Protocol | Baud |
|---|---|---|---|
| GPS1 (UART) | GPS/compass module | u-blox UBX + NMEA | 38400 or 115200 |
| TELEM1 (UART) | SiK telemetry radio | MAVLink 2 | 57600 |
| TELEM2 (UART) | ESP32 UART (TX/RX) | MAVLink 2 | 115200 |
| SERIAL5 (or spare) | RPLidar A1 UART | LIDAR serial | 115200 |
| RC IN | RC receiver SBUS/PPM | SBUS / PPM | — |
| Safety SW | Arming button | GPIO | — |
| ADC/Power | Power module | Analog | — |

### FC PWM Output Channels

| FC Output | Connected to | ArduRover function |
|---|---|---|
| CH1 | ESC Left (3× motors) | Throttle left (skid-steer) |
| CH3 | ESC Right (3× motors) | Throttle right (skid-steer) |
| CH2 | Front steering servo pair | Steering output |
| CH4 | Rear steering servo pair | Steering output |

> Exact channel assignments will depend on FC model and servo output configuration.
> Configure via `SERVO1_FUNCTION`, `SERVO3_FUNCTION` etc. in ArduRover params.

### I2C Compass

- GPS module compass connected to FC I2C compass port (separate from ESP32 I2C bus)

---

## Power Rail Summary

| Rail | Source | Consumers |
|---|---|---|
| 12V main | Battery → PDB | Both ESCs, BEC inputs |
| 5V servo rail | BEC 1 (5A min) | All 13 servos via PCA9685 |
| 5V logic rail | BEC 2 | FC, ESP32, RPLidar, RC receiver |
| 5V (FC internal) | FC BEC or USB | FC processor only |

**Fusing:**
- Main: 30–40A blade fuse between battery and PDB
- Servo rail: polyfuse or 5A blade fuse per BEC output recommended
- Motor circuits: fused through ESC internal protection

---

## Wiring Diagram

> ⚠️ Full annotated schematic TBD — to be drawn in KiCad or draw.io and exported as SVG/PDF.
> Target: `docs/wiring-diagram/redrover-full-schematic.svg`

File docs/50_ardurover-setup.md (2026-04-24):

# ArduRover Setup

Configuration guide for the ArduRover autopilot on the RedRover.
ArduRover replaces the ESP32 as the motion controller for drive and navigation;
see [70_firmware-esp32.md](70_firmware-esp32.md) for how the ESP32 is refactored to work alongside it.

Parameter files live in `ardurover/params/`.

---

## Hardware Prerequisites

Before configuring ArduRover, the following must be physically connected:

- [ ] Flight controller mounted on vibration isolation foam, arrow pointing forward
- [ ] GPS/compass module connected to FC GPS1 UART + I2C compass port
- [ ] RC receiver connected to FC RC IN (SBUS or PPM)
- [ ] Both ESCs signal wires routed to FC PWM output channels
- [ ] SiK telemetry radio connected to FC TELEM1
- [ ] ESP32 UART connected to FC TELEM2
- [ ] RPLidar UART connected to FC SERIAL5 (or appropriate spare serial port)
- [ ] Power module connected between battery and FC power input

---

## Initial Connection

1. Connect SiK radio to GCS computer (see [60_gcs-setup.md](60_gcs-setup.md))
2. Open Mission Planner → Connect → select SiK COM port → 57600 baud
3. Flash latest ArduRover stable firmware via Mission Planner **Initial Setup → Install Firmware**
   - Select "Rover" vehicle type
4. Perform mandatory hardware calibration (see below) before first parameter load

---

## Mandatory Calibration Sequence

Complete all of these before loading the baseline param file.

### 1. Accelerometer calibration
Mission Planner → Initial Setup → Mandatory Hardware → Accel Calibration
- Follow on-screen 6-position calibration (flat, left, right, nose-up, nose-down, back)

### 2. Compass calibration
Mission Planner → Initial Setup → Mandatory Hardware → Compass
- Select external compass (GPS module compass), disable internal FC compass if present
- Run onsite calibration — rotate rover through all axes until bars fill

### 3. RC calibration
Mission Planner → Initial Setup → Mandatory Hardware → Radio Calibration
- Move all sticks and switches to extremes
- Verify channel assignments match expected (Throttle = CH2, Steering = CH1)

### 4. ESC calibration
Mission Planner → Optional Hardware → Motor Test
- Set `MOT_PWM_MIN` and `MOT_PWM_MAX` to match ESC endpoints
- Run motor test at 5–10% to verify correct rotation direction
- Swap ESC signal wires if motor direction is wrong

---

## Baseline Parameter File

`ardurover/params/redrover_base.param` — TBD, load after calibrations are saved.

Key parameter groups to configure:

### Frame type (skid-steer)
```
SERVO1_FUNCTION = 73    ; throttle left
SERVO3_FUNCTION = 74    ; throttle right
```
> Adjust channel numbers to match your physical wiring. For Ackermann (independent
> corner steering), use `SERVO1_FUNCTION=26` (steering) + `SERVO3_FUNCTION=70` (throttle).

### GPS
```
GPS_TYPE  = 1           ; u-blox auto-detect
GPS_NAVFILTER = 8       ; automotive (good default for ground vehicle)
GPS_HDOP_GOOD = 140     ; HDOP threshold for arming (1.4 = tight, loosen if needed outdoors)
SERIAL3_PROTOCOL = 5    ; GPS on SERIAL3 (adjust port number per FC)
SERIAL3_BAUD = 38        ; 38400 baud
```

### Compass
```
COMPASS_USE    = 1
COMPASS_USE2   = 0       ; disable internal compass if external present
COMPASS_ORIENT = 0       ; adjust if GPS module is not mounted arrow-forward
```

### Battery monitor
```
BATT_MONITOR   = 4       ; voltage + current via power module
BATT_VOLT_PIN  = varies  ; check FC pinout
BATT_CURR_PIN  = varies
BATT_VOLT_MULT = varies  ; calibrate against known voltage
BATT_AMP_PERVLT = varies ; calibrate against known current
BATT_LOW_VOLT  = 10.5    ; 3S low voltage warning (3.5V/cell)
BATT_CRT_VOLT  = 10.2    ; 3S critical — trigger failsafe
```

### Telemetry
```
SERIAL1_PROTOCOL = 2    ; MAVLink 2 on TELEM1 (SiK radio)
SERIAL1_BAUD     = 57   ; 57600
SERIAL2_PROTOCOL = 2    ; MAVLink 2 on TELEM2 (ESP32)
SERIAL2_BAUD     = 115  ; 115200
```

### Failsafes
```
FS_ACTION    = 2         ; RTL on RC failsafe
FS_TIMEOUT   = 1.5       ; seconds before failsafe triggers
BATT_FS_VOLTAGE_ACTION = 2  ; RTL on low battery
```

---

## LiDAR / Proximity Sensor Setup (RPLidar A1)

```
PRX_TYPE     = 5         ; RPLidar
PRX_ORIENT   = 0         ; 0 = forward, adjust if rotated
PRX_YAW_CORR = 0         ; yaw offset correction in degrees
SERIAL5_PROTOCOL = 11   ; proximity sensor on SERIAL5 (adjust port)
SERIAL5_BAUD = 115       ; 115200
```

Collision avoidance:
```
AVOID_ENABLE  = 7        ; enable all avoidance
AVOID_MARGIN  = 2.0      ; stop/steer when obstacle within 2 m
AVOID_BEHAVE  = 1        ; 0=slide, 1=stop
```

### TFMini-Plus (alternative single-point)
```
RNGFND1_TYPE     = 20    ; TFMini
RNGFND1_MIN_CM   = 10
RNGFND1_MAX_CM   = 600
RNGFND1_ORIENT   = 0     ; forward-facing
SERIAL5_PROTOCOL = 9     ; rangefinder
SERIAL5_BAUD     = 115
```

---

## Navigation & Waypoint Tuning

### Waypoint following
```
WP_RADIUS    = 0.5       ; waypoint achieved within 0.5 m
WP_SPEED     = 1.0       ; m/s default cruise speed
```

### RTL (Return to Launch)
```
RTL_RADIUS   = 1.0       ; orbit radius at home point
TURN_MAX_G   = 0.5       ; max lateral G in turns
```

### Steering rate controller (tune after basic driving works)
```
ATC_STR_RAT_MAX  = 120   ; degrees/sec max turn rate
ATC_STR_RAT_P    = 0.2   ; starting proportional gain
ATC_STR_RAT_I    = 0.1
ATC_STR_RAT_D    = 0.005
```

---

## SITL (Software In The Loop) Testing

Before using on hardware, validate parameter changes in ArduRover SITL.

### Setup (WSL or Linux VM)
```bash
# Install ArduPilot deps (Ubuntu/Debian)
sudo apt install git python3 python3-pip python3-dev
pip3 install mavproxy

# Clone ArduPilot
git clone --recurse-submodules https://github.com/ArduPilot/ardupilot.git
cd ardupilot
Tools/environment_install/install-prereqs-ubuntu.sh -y
. ~/.profile

# Run ArduRover SITL
sim_vehicle.py -v Rover --console --map
```

### Connect QGroundControl to SITL
- QGC → Application Settings → Comm Links → Add → UDP → port 14550
- SITL broadcasts MAVLink on UDP 14550 by default

---

## Geofence

```
FENCE_ENABLE  = 1
FENCE_TYPE    = 2        ; polygon
FENCE_ACTION  = 1        ; RTL on breach
FENCE_RADIUS  = 50       ; fallback circle fence radius in metres
```

Draw polygon fence in Mission Planner → Flight Plan → Fence before first autonomous test.

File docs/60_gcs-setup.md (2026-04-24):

# Ground Control Station Setup

How to connect a GCS to the RedRover for configuration, monitoring, and autonomous mission control.

---

## GCS Software Options

| Application | Platform | Best for |
|---|---|---|
| **Mission Planner** | Windows | Full ArduRover parameter editing, initial setup, calibration |
| **QGroundControl** | Windows / macOS / Linux / Android | Mission planning, field monitoring, clean UI |

Recommendation: use **Mission Planner** for initial setup and calibration, then
**QGroundControl** (QGC) for day-to-day field use. Both support MAVLink 2.

---

## Connection via SiK Telemetry Radio

The primary GCS link uses a SiK 915 MHz radio pair (e.g. RFD900x or HolyBro SiK v3):
- One radio connected to ArduRover FC TELEM1 port (on the rover)
- One radio connected to GCS laptop via USB

### Mission Planner
1. Plug GCS radio into USB port — note COM port assigned (Device Manager)
2. Open Mission Planner → top-right dropdown: select COM port, set baud to **57600**
3. Click **Connect** — wait for parameter download (~30 sec on first connect)

### QGroundControl
1. QGC auto-detects SiK radio on USB — connection banner should appear
2. If not auto-detected: Application Settings → Comm Links → Add → Serial → select port → 57600

---

## Connection via WiFi (ESP32 hosted web UI)

The ESP32 can host a WiFi AP for browser-based control (no GCS software needed).

1. Set rover boot mode switch to `ROVER_SWITCH_STATE_AP` (see [70_firmware-esp32.md](70_firmware-esp32.md))
2. Connect laptop/phone to WiFi SSID **"Rover"**
3. Navigate to `http://192.168.4.1` in browser
4. Virtual joystick UI loads — WebSocket connects automatically

> This path bypasses ArduRover — it controls the ESP32 directly for arm/head servos
> and (in the original firmware) direct motor drive. Post-refactor it will be a
> MAVLink telemetry dashboard rather than a direct motion controller.

---

## MAVLink Telemetry via ESP32 WiFi Bridge (RedRover planned)

After the ESP32 MAVLink refactor ([70_firmware-esp32.md](70_firmware-esp32.md)):

1. ESP32 bridges MAVLink from FC TELEM2 over WiFi WebSocket
2. QGC can connect via UDP: Application Settings → Comm Links → Add → UDP → port 14550
3. Or use MAVLink2Rest running on ESP32 companion

---

## First Field Session Checklist

### Before leaving the bench
- [ ] SiK radios paired and link LED solid on both units
- [ ] Mission Planner connects and downloads parameters cleanly
- [ ] GPS fix acquired indoors or near window (HDOP < 1.4)
- [ ] Battery monitor reading correct voltage in MP HUD
- [ ] All RC channels reading correct values in MP Radio Calibration screen

### At the field
- [ ] Set home point (Mission Planner → right-click map → Set Home Here) or confirm GPS auto-home
- [ ] Draw polygon geofence appropriate to test area
- [ ] Arm rover (safety button → hold RC arm switch or MP arm button)
- [ ] Test MANUAL mode first — verify steering direction and motor direction
- [ ] Test HOLD mode — rover should stop and hold position
- [ ] Test simple 3-waypoint AUTO mission before longer routes
- [ ] Keep hand on RC transmitter to switch back to MANUAL at any time

---

## Driving Modes Reference

| Mode | ArduRover name | Behaviour |
|---|---|---|
| MANUAL | `MANUAL` | Direct RC passthrough to ESCs — no autopilot intervention |
| HOLD | `HOLD` | Stop and hold current position |
| STEERING | `STEERING` | Autopilot stabilises heading; throttle from RC |
| AUTO | `AUTO` | Follows uploaded waypoint mission |
| GUIDED | `GUIDED` | Fly-to-point commands from GCS map click |
| RTL | `RTL` | Return to GPS home point and stop |

---

## Useful MAVLink Shell Commands (MAVProxy)

```bash
mavproxy.py --master=/dev/ttyUSB0 --baud=57600

# Check modes
mode MANUAL
mode AUTO

# Arm / disarm
arm throttle
disarm

# Request parameter
param fetch
param show WP_RADIUS

# Upload mission from file
wp load my_mission.txt
wp set 1       # jump to waypoint 1

# Stream position
set streamrate 4
```

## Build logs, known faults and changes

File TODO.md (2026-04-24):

# RedRover — Project TODO

A Curiosity/Perseverance-inspired rover, forked from [jakkra/Mars-Rover](https://github.com/jakkra/Mars-Rover),
rebuilt with ArduRover, GPS, and LiDAR-based collision avoidance.

---

## Priority 1 — Print & Assembly

- [ ] **Bill of Materials (BOM)**
  - Enumerate every 3D-printed part from the Fusion 360 model, with quantity and suggested material (PLA/PETG/TPU)
  - List all off-the-shelf hardware: M3/M4 fasteners, 608ZZ & SKF 6005 bearings, PVC pipe (ID 23.40 mm / OD 25 mm), motor shaft adapters (Pololu #1081), servo horns
  - Add all electronics (see Electrical section below) to the BOM with supplier links

- [ ] **Slicer settings document**
  - Recommended layer height, infill % and pattern per part category (structural vs. cosmetic)
  - Identify parts that require supports, brim, or special orientation
  - Flag TPU wheel outer skin print settings separately (print speed, retraction, bed adhesion)
  - Note which parts are mirrored vs. unique

- [ ] **Print sequence / dependency order**
  - Order parts by sub-assembly so printing isn't blocked by missing pieces
  - Flag long prints that should run overnight

- [ ] **Assembly guide — Rocker-Bogie suspension**
  - Step-by-step with reference screenshots pulled from the Fusion 360 model
  - Bearing press-fit tolerances and notes on reaming holes if needed
  - Rocker-bogie pivot alignment procedure

- [ ] **Assembly guide — Drive train**
  - Motor mounting and shaft-coupler installation
  - ESC bracket placement and strain-relief routing
  - Corner steering servo installation and centering procedure

- [ ] **Assembly guide — Arm (6-DOF)**
  - Joint assembly order
  - Servo horn drilling / tapping guide
  - Cable management through hollow links

- [ ] **Assembly guide — Head**
  - Yaw/pitch servo installation
  - Camera/sensor mounting provisions

- [ ] **Assembly guide — Electronics bay**
  - Panel layout diagram (flight controller, ESP32, power distribution, telemetry, GPS, LiDAR)
  - Lid fitment and access hatch notes

- [ ] **Wiring diagram**
  - Full schematic: battery → power module → PDB → ESCs, servo rail, 5 V regulators, flight controller, ESP32
  - Annotated connector callouts (XT60, JST, Dupont, RJ45 for telemetry)

---

## Priority 2 — Electrical (Hardware Gaps)

> The original design runs everything from a single ESP32. Adding ArduRover requires a dedicated
> autopilot board and supporting electronics.

- [ ] **Flight controller (ArduRover host)**
  - Select and source autopilot: Pixhawk 6C / Matek H743-Wing / CubePilot Orange+ (recommended for reliability)
  - Mount inside electronics bay with vibration isolation foam

- [ ] **GPS / compass module**
  - u-blox M8N or M9N with integrated compass (e.g., Here3, mRo GPS)
  - Design/print elevated GPS mast to reduce airframe interference
  - Wire: UART to ArduRover GPS1 port, I2C compass to I2C bus

- [ ] **LiDAR sensor for collision avoidance**
  - Select sensor: RPLidar A1M8 (360° scan, ~$100) or TFMini-Plus (single-point, cheaper)
    - RPLidar preferred for full-perimeter avoidance via ArduRover `PRX_TYPE` proximity framework
  - Power: 5 V regulated supply, ~450 mA peak
  - Interface: UART to autopilot serial port (or USB→UART to companion if RPLidar)
  - Mount: top deck centered for unobstructed 360° view (RPLidar) or front-facing (TFMini)

- [ ] **Telemetry radio**
  - SiK 915 MHz radio pair (RFD900x or HolyBro SiK v3) — one on rover, one on GCS laptop/tablet
  - Keeps the existing LoRa link for ESP32 peripheral comms (separate frequency/protocol)
  - Wire to ArduRover TELEM1 port (UART)

- [ ] **Power module / battery monitoring**
  - ArduRover-compatible power module (e.g., Matek HUBOSD or Holybro PM02) between 3S LiPo and PDB
  - Provides VBAT + current sense to autopilot ADC — needed for low-voltage failsafe and telemetry

- [ ] **Power distribution board (PDB)**
  - Route 12 V from battery to: both drive ESCs, servo power rail (via 12 V→5 V BECs), autopilot 5 V rail, RPLidar 5 V, ESP32 5 V
  - Replace the 12× individual 12 V→5 V regulators with 2–3 high-current BECs (e.g., Matek MBEC6S 5 A each) to reduce wiring complexity

- [ ] **ESC integration into autopilot**
  - Wire both brushless ESC signal wires to ArduRover PWM output channels (CH1 = left, CH3 = right, or skid-steer config)
  - Calibrate ESC endpoints via ArduRover motor test

- [ ] **Steering servo integration into autopilot**
  - Wire 4 corner steering servos to ArduRover PWM output channels
  - Determine if Ackermann or independent corner steering mode is used in ArduRover

- [ ] **ESP32 role redefinition**
  - ESP32 (TTGO LoRa32) demoted to companion/peripheral role
  - Connects to autopilot via UART (MAVLink passthrough) or acts as WiFi telemetry bridge
  - Arm, head, and auxiliary servos remain on ESP32 / PCA9685 servo driver
  - Remove direct motor/ESC control from ESP32 firmware

- [ ] **RC receiver wiring**
  - Route RC receiver SBUS/PPM output to ArduRover RC IN port (was wired directly to ESP32 GPIO)
  - ESP32 can still sniff RC channels via MAVLink RC override if needed

- [ ] **Arming switch / safety switch**
  - Add physical arming button wired to ArduRover safety switch port (required for ArduRover arming sequence)

- [ ] **Current budget and fuse sizing**
  - Document peak current draw for all loads
  - Size main fuse (recommend blade fuse holder, 30–40 A)
  - Add per-rail polyfuses or blade fuses for servo rails

---

## Priority 3 — Firmware & Software (Programmatic Gaps)

> The current codebase is a self-contained ESP32 firmware. ArduRover replaces the motion control
> layer; the ESP32 becomes a peripheral. A ground control station (GCS) replaces the custom web UI
> for autopilot functions.

### ArduRover Configuration

- [ ] **Initial ArduRover parameter file**
  - Create `ardurover/params/redrover_base.param` with baseline settings:
    - Frame type: skid-steer (`SERVO1_FUNCTION=73`, `SERVO3_FUNCTION=74`) or Ackermann
    - GPS, compass, AHRS orientation
    - Telemetry baud rates
    - Battery monitor type and scale factors
  - Document parameter rationale inline as comments

- [ ] **ESC / motor calibration procedure**
  - Document ArduRover motor test steps and PWM min/max tuning

- [ ] **Steering geometry calibration**
  - Ackermann steer turn radius calculation from CAD dimensions
  - `ATC_STR_RAT_MAX`, `TURN_MAX_G` parameter tuning notes

- [ ] **Compass/GPS calibration procedure**
  - Live calibration steps in Mission Planner / QGroundControl
  - Notes on compass interference sources on the rover frame

### LiDAR / Collision Avoidance

- [ ] **ArduRover proximity sensor setup (RPLidar)**
  - Set `PRX_TYPE=5` (RPLidar) and configure serial port
  - Configure `PRX_ORIENT`, `PRX_YAW_CORR` for physical mounting offset
  - Enable object avoidance: `AVOID_ENABLE=7`, `AVOID_MARGIN`, `AVOID_BEHAVE`

- [ ] **LiDAR driver integration (if using companion computer)**
  - ROS2 / Python node to publish `/scan` topic and forward to ArduRover via MAVLink `DISTANCE_SENSOR` messages
  - Alternatively: direct UART from RPLidar to autopilot serial using ArduRover built-in driver (no companion needed for A1)

- [ ] **TFMini-Plus fallback (single-point)**
  - Configure as `RNGFND1_TYPE=20`, set `RNGFND1_MAX_CM`, `RNGFND1_MIN_CM`
  - Wire and test before full RPLidar integration

- [ ] **Geofence setup**
  - Define a test-area polygon geofence in Mission Planner
  - Set `FENCE_ACTION=1` (RTL on breach) for initial field testing

### GPS & Navigation

- [ ] **GPS driver and port assignment**
  - Set `GPS_TYPE=1` (u-blox auto-detect), assign to correct SERIAL port
  - Verify HDOP threshold for arming (`GPS_HDOP_GOOD`)

- [ ] **Waypoint mission test**
  - Create a simple 5-waypoint square loop mission in QGroundControl
  - Test AUTO mode with and without collision avoidance enabled

- [ ] **RTL (Return to Launch) tuning**
  - Set and test `RTL_RADIUS`, `WP_RADIUS`
  - Validate GPS home point lock before arming

### ESP32 Firmware Refactor

- [ ] **MAVLink integration on ESP32**
  - Add `mavlink` library to `platformio.ini`
  - Implement MAVLink heartbeat RX/TX on Serial2 (UART link to autopilot)
  - Forward arm/disarm commands and RC override channels if needed

- [ ] **Remove direct ESC/motor control from ESP32**
  - `rover_driving.cpp` motor PWM output → disabled or redirected to MAVLink RC override
  - Retain servo control for arm and head (still managed by ESP32 / PCA9685)

- [ ] **Telemetry bridge (optional)**
  - ESP32 bridges MAVLink telemetry over WiFi websocket to a browser-based GCS (e.g., MAVLink2Rest or custom)
  - Exposes heading, GPS position, battery, mode on existing web UI

- [ ] **Arm inverse kinematics (carried over TODO)**
  - Implement IK solver for 6-DOF arm (was explicitly TODO in original codebase)
  - Consider FABRIK or analytical 6-DOF solution
  - Expose IK target coordinates via RC channels or websocket command

- [ ] **Web UI overhaul**
  - Replace joystick-only page with a dashboard:
    - MAVLink mode selector (MANUAL / AUTO / GUIDED / RTL)
    - Battery voltage / current gauge
    - GPS fix status and position
    - LiDAR proximity ring visualization
    - Arm control panel (IK target input)

### Ground Control Station

- [ ] **GCS software selection and setup**
  - Install Mission Planner (Windows) or QGroundControl (cross-platform)
  - Connect via SiK telemetry radio
  - Document connection steps in a `docs/gcs-setup.md`

- [ ] **SITL (Software-in-the-Loop) test environment**
  - Set up ArduRover SITL on WSL or Linux VM for parameter validation before hardware
  - Document launch command and how to connect QGC to SITL

---

## Priority 4 — Documentation & Repository Structure

- [ ] **Folder structure for RedRover repo**
  - Decide what lives in the fork vs. a separate RedRover repo
  - Suggested layout:
    ```
    RedRover/
      Mars-Rover/          ← upstream fork (CAD + ESP32 firmware)
      ardurover/
        params/            ← .param files
        docs/              ← calibration & setup guides
      docs/
        bom.md
        print-settings.md
        assembly/
          suspension.md
          drivetrain.md
          arm.md
          electronics-bay.md
        wiring-diagram.pdf (or .svg)
        gcs-setup.md
      TODO.md              ← this file
    ```

- [ ] **Upstream sync strategy**
  - Decide on branch strategy: maintain a `redrover` branch in the fork, periodically rebase onto upstream `main`
  - Document in `CONTRIBUTING.md` what changes stay in-fork vs. go upstream

- [ ] **CHANGELOG / build log**
  - Running log of hardware decisions, part substitutions, and lessons learned

---

---

## Priority 5 — 3D Print File Organization

> **Context:** `3d-prints/` contains **295 STL files totalling ~329 MB** exported from the full
> Fusion 360 assembly. Most of the bulk is high-poly CAD reference meshes of purchased parts
> (servos, bearings, motors) that must never be sent to a slicer. The actual printable count is
> roughly 80–100 files. Goal: quarantine context-only files, then sort printable parts into
> sub-assembly packs kept under **10 MB raw** (slicer project files add overhead on top).

### Step 1 — Quarantine context-only models (DO NOT PRINT) ✅

Create `3d-prints/_context_only/` and move the following in. None of these are printed — they are
purchased hardware reference geometry used in the assembly for spatial planning.

- [x] **Servo MG996R bodies** — every file matching `*Servo MG996R v2*Body[1-9]*.stl`
  (Body1 = housing ~2–3 MB, Body2 = case cover ~2–6 MB, Body3–7 = internals/screws ~28–840 KB each)
  Affects: rover core steering servos (×8), arm servos (servo_and_horn v2 instances ×4),
  head servos (×2). **Exception: the `servo_and_horn v2 (N)_1_Body1.stl` files are the
  3D-printed servo horn — keep those in their assembly packs below.**

- [x] **Gripper servo** — `*gripper_Assy_V3*Servo v1_1_Body1.stl` and `Body2.stl` (~257 KB, ~490 KB)

- [x] **Ball Bearing 608ZZ** — all three instances (`v1_1`, `v1_2`, arm `v1_3`),
  20 bodies each. The large ones (Body8 = 9.5 MB, Body9 = 9.3 MB, Body19 = 6.5 MB, Body20 = 7.7 MB)
  account for most of the 329 MB total. This group alone is ~150 MB.

- [x] **SKF 6005 25mm Bearings** — `*25mm Bearing SKF 6005*` (12 bodies, ~715 KB + 11 × ~139 KB)

- [x] **DC Motors** — `*DC-motor v10*Body1.stl` and mirror variant (~227 KB each)

- [x] **Pololu shaft hub** — `*pololu-universal-aluminum-mounting-hub*` (~1.2 MB, purchased part)

- [x] **McMaster fasteners** — `*90592A085*` (7 instances × ~3.3 MB each = ~23 MB) and
  `*90965A130*` (~50 KB) — these are hex bolt/nut reference models

- [ ] **Review before printing** — `*Rover core v232_1_Body46.stl` (7.3 KB — likely a tiny hardware
  reference). Cross-check any Rover core `Body*.stl` under 50 KB against the CAD before including
  in a print pack.

---

### Step 2 — Organize printable parts into print packs

Create sub-folders under `3d-prints/` as below. Each pack should be under ~10 MB raw STL.
After sorting, import each folder into your slicer as a project to add print profiles/supports.

> **Naming convention:** `NN_description/` with two-digit prefix for print order.

---

#### Pack 01 — Chassis Body Panels (~3.6 MB)
`3d-prints/01_chassis_body/`

- [ ] Move all `Rover body_Rover_Full_Body*.stl` (Body1, 3, 4, 5, 6, 7, 9, 10, 13, 14, 15, 16 — 12 files, ~3.1 MB)
- [ ] Move `Rover body_Rover_Full_Lid1.stl` (~592 KB)
- **Notes:** These are the outer hull plates and electronics bay lid. Likely PETG or PLA+. Check
  for living-hinge or snap features that may need specific orientation.

---

#### Pack 02 — Head Assembly Part 1 (~3.8 MB)
`3d-prints/02_head_pack1/`

- [ ] `*head_rotator_1_Body1/2/3.stl` (yaw rotator bracket, ~475 KB total)
- [ ] `*head_rotator_1_head_1_Body1/2/3/4.stl` (head housing, ~994 KB total)
- [ ] `*espcam_holder_1_Body1/2.stl` (camera mount, ~48 KB total)
- [ ] `*head_top_connector_1_Body1/2/3/4/5/6/9/10/11/15.stl` (smaller connector parts, ~2.3 MB)
- [ ] Move both `servo_and_horn v2 (4)_1_Body1.stl` and `v2 (5)_1_Body1.stl` here
  (the **printed** servo horns for head yaw + pitch, ~109 KB each)
- **Notes:** Head houses ESP32-CAM. Plan sensor mast provisions here for LiDAR/GPS if mounting on head.

---

#### Pack 03 — Head Assembly Part 2 (~2.2 MB)
`3d-prints/03_head_pack2/`

- [ ] `*head_top_connector_1_Body7.stl` (~1.3 MB — largest head part)
- [ ] `*head_top_connector_1_Body8.stl` (~881 KB)
- [ ] `*head_top_connector_1_Body13/14.stl` (~464 KB + ~202 KB)
- **Notes:** Body7 is the largest single head part — verify print orientation for overhang.

---

#### Pack 04 — Arm Structure (~4.5 MB)
`3d-prints/04_arm_structure/`

- [ ] `*arm_1_1_Body1.stl` (first arm link, ~1.1 MB)
- [ ] `*arm_1_1_body_connector_1_Body1.stl` (~852 KB)
- [ ] `*arm_body_connector_1_Body1.stl` (base to arm connector, ~348 KB)
- [ ] `*arm2_1_Body1.stl` and `arm2_1_Body2.stl` (second link, ~329 KB + ~229 KB)
- [ ] `*arm2(Mirror)(Mirror)_1_Body1.stl` and `Body2.stl` (mirror of above for other side, ~326 KB + ~228 KB)
- [ ] `*arm3_1_Body1.stl` (third arm link, ~1.2 MB)
- **Notes:** arm2 and its mirror may require different print orientations for layer strength.
  Consider printing arm links in PETG for toughness.

---

#### Pack 05 — Arm Gripper Connector & Servo Horns (~2.6 MB)
`3d-prints/05_arm_gripper_connector/`

- [ ] `*arm_gripper_connector_1_Body1.stl` (~874 KB)
- [ ] `*arm_gripper_connector_1_Body2.stl` (~374 KB)
- [ ] `*arm_gripper_connector_1_grip_rotator_1_Body1.stl` (~987 KB)
- [ ] `*arm_1_1_servo_and_horn v2 (1)_1_Body1.stl` (printed arm servo horn, ~109 KB)
- [ ] `*arm_gripper_connector_1_servo_and_horn v2 (2)_1_Body1.stl` (~108 KB)
- [ ] `*arm_gripper_connector_1_grip_rotator_1_servo_and_horn v2 (3)_1_Body1.stl` (~108 KB)
- **Notes:** The three `Body1` servo horn files here are the **only printable parts** in those
  servo_and_horn sub-assemblies — all sibling `Servo MG996R v2_*_Body*` files go to _context_only.

---

#### Pack 06 — Gripper Finger Assembly (~4.3 MB)
`3d-prints/06_gripper_fingers/`

- [ ] `*gripper_Assy_V3*gear_horn25T_L*Body1.stl` (~799 KB)
- [ ] `*gripper_Assy_V3*gear_horn25T_R*Body1.stl` (~307 KB)
- [ ] `*gripper_Assy_V3*lower_arm_L*Body1.stl` (~151 KB)
- [ ] `*gripper_Assy_V3*lower_arm_R*Body1.stl` (~151 KB)
- [ ] `*gripper_Assy_V3*lower_plate*Body1.stl` (~590 KB)
- [ ] `*gripper_Assy_V3*middle_plate*Body1.stl` (~595 KB)
- [ ] `*gripper_Assy_V3*rear_*plate_horn25T*Body1.stl` (~207 KB)
- [ ] `*gripper_Assy_V3*rod (X4)*_1_Body1.stl` through `_4_Body1.stl` (×4, ~494 KB each = ~1.98 MB)
- [ ] `*gripper_Assy_V3*upper_arm_L*Body1.stl` (~163 KB)
- [ ] `*gripper_Assy_V3*upper_arm_R*Body1.stl` (~163 KB)
- [ ] `*gripper_Assy_V3*upper_plate*Body1.stl` (~307 KB)
- **Notes:** 4× rods are identical — print all 4 in one plate. The gear horns are mirrored;
  verify chirality before printing.

---

#### Pack 07 — Suspension Connectors (~4.9 MB)
`3d-prints/07_suspension_connectors/`

- [ ] `*back_two_wheel_connector_1_Body1.stl` (~698 KB)
- [ ] `*back_two_wheel_connector(Mirror)_1_Body1.stl` (~699 KB)
- [ ] `*main_leg_body_connector_1_Body1.stl` (~1.78 MB)
- [ ] `*main_leg_body_connector(Mirror)_1_Body1.stl` (~1.79 MB)
- **Notes:** These are the rocker-bogie pivot connectors — high stress parts. PETG or ABS
  recommended. The mirror pairs are left/right; print one of each side ×2 total (one per bogie).

---

#### Pack 08 — Wheel Hub & Axle Small Parts (~4.9 MB)
`3d-prints/08_wheel_hub_smalls/`

- [ ] `*corner_wheel2_1_Body2.stl` (~591 KB)
- [ ] `*corner_wheel2_1_Body3.stl` (~403 KB)
- [ ] `*corner_wheel2_1_Body4.stl` (~548 KB)
- [ ] `*corner_wheel2_1_Body5.stl` (~428 KB)
- [ ] `*corner_wheel2_1_Body6.stl` (~119 KB)
- [ ] `*corner_wheel2_1_Body7.stl` (~550 KB)
- [ ] `*corner_wheel2_1_Body9.stl` (~550 KB)
- [ ] `*corner_wheel2_1_Body10.stl` (~403 KB)
- [ ] `*middle_wheel_1_Body1.stl` (~403 KB)
- [ ] `*middle_wheel_1_Body2.stl` (~591 KB)
- [ ] `*middle_wheel_1_Body5.stl` (~403 KB)
- **Notes:** These are the hub faces, axle flanges, and steering knuckle small bodies.
  Note: corner_wheel2 is used ×4 (one per corner) — print multiples as needed.

---

#### Pack 09 — Corner Wheel Shell A (~4.0 MB)
`3d-prints/09_wheel_corner_A/`

- [ ] `*corner_wheel2_1_Body1.stl` (~4.0 MB — the main corner wheel outer shell)
- **Notes:** This is a large single part. Verify it fits your print bed. Needs 4 total — print 1
  to validate fit, then run the remaining 3.

---

#### Pack 10 — Corner Wheel Shell B (~4.1 MB)
`3d-prints/10_wheel_corner_B/`

- [ ] `*corner_wheel2_1_Body8.stl` (~4.1 MB — the corner wheel inner shell / TPU candidate)
- **Notes:** If printing the Mars 2020-style flexible wheel outer, use TPU here. Separate slicer
  profile required. Need 4 total.

---

#### Pack 11 — Middle Wheel Shell A (~4.0 MB)
`3d-prints/11_wheel_middle_A/`

- [ ] `*middle_wheel_1_Body3.stl` (~4.0 MB)
- **Notes:** Middle wheel outer skin. Need 2 total (one per side). TPU candidate if using flex wheels.

---

#### Pack 12 — Middle Wheel Shell B (~4.1 MB)
`3d-prints/12_wheel_middle_B/`

- [ ] `*middle_wheel_1_Body4.stl` (~4.1 MB)
- **Notes:** Middle wheel inner body. Need 2 total.

---

#### Packs 13–17 — Rover Core Structure Body Parts (~28 MB across 5 packs)
> The 54 numbered `Rover core v232_1_Body*.stl` files are generic structural parts
> (frame rails, motor mounts, axle housings, brackets). They have no named sub-assembly
> context, so these are binned by size into safe packs. **Cross-reference each body
> number against the Fusion 360 model before printing to confirm it is not a hardware
> reference** — especially any file under 50 KB.

- [ ] **Pack 13** `3d-prints/13_core_structure_A/` — Body6 (~4.0 MB) + Body33 (~4.2 MB) = ~8.2 MB
  *(The two largest single bodies; each is near the 10 MB limit solo with slicer overhead)*

- [ ] **Pack 14** `3d-prints/14_core_structure_B/` — Body3 + Body16 + Body25 + Body26 + Body28 + Body38
  (~1.1 + ~1.2 + ~0.9 + ~0.9 + ~1.1 + ~1.5 MB = ~6.7 MB)

- [ ] **Pack 15** `3d-prints/15_core_structure_C/` — Body1 + Body2 + Body4 + Body5 + Body7 + Body8 + Body9 + Body10 + Body11 + Body12 + Body13 + Body14
  (~425+118+401+651+320+584+535+231+792+138+559+183 KB = ~4.9 MB)

- [ ] **Pack 16** `3d-prints/16_core_structure_D/` — Body15 + Body17 + Body18 + Body19 + Body20 + Body21 + Body22 + Body23 + Body24 + Body27 + Body29 + Body30
  (~543+213+526+154+84+154+213+234+84+792+401+538 KB = ~3.9 MB)

- [ ] **Pack 17** `3d-prints/17_core_structure_E/` — Body31 + Body32 + Body34 + Body35 + Body36 + Body37 + Body39 + Body40 + Body41 + Body42 + Body43 + Body44 + Body45 + Body46\* + Body47 + Body48 + Body49 + Body50 + Body51 + Body52 + Body53 + Body54
  (~5.1 MB total) *\*Body46 = 7.3 KB — flag for CAD review before printing*

---

### Step 3 — Post-sort validation

- [ ] Confirm `3d-prints/` root is empty after all files are moved — no orphans left behind
- [ ] Verify total file count across all print packs matches count of printable originals
- [ ] Spot-check 3–4 files per pack by opening in slicer to confirm geometry is valid and
  not inside-out / zero-volume
- [ ] Add a `3d-prints/README.md` listing pack descriptions, recommended materials, and
  quantities per part

---

## Parking Lot / Future

- [ ] Camera feed (CSI or USB cam) streamed to GCS or web UI
- [ ] Companion computer (Raspberry Pi 5 / Jetson Orin Nano) for vision-based SLAM
- [ ] ROS2 integration for advanced mission execution
- [ ] Solar charging panel on lid for extended outdoor operation
- [ ] Weatherproofing / IP rating for electronics bay
- [ ] Custom antenna tracker using second LoRa + GPS module
- [ ] Simulation model export (Gazebo / Isaac Sim URDF from Fusion 360)

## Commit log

2026-04-24 Initial commit — RedRover project scaffold
    - README with project overview and repo structure
    - TODO.md with full scope (print/assembly, electrical, firmware, docs)
    - Mars-Rover added as git submodule (FortiJeremy/Mars-Rover @ 94ccec0)
    - .gitignore for OS/editor artifacts and build outputs
2026-04-24 Initial 3d-print breakout, moved obvious parts to context_only folder, will begin consolidating and building 3mf files with multi-plate from here.
    [Rover body_Rover_Full_Body1.stl, Rover body_Rover_Full_Body10.stl, Rover body_Rover_Full_Body13.stl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]
2026-04-25 Remove 3d-prints from tracking — pending re-export
    [Rover body_Rover_Full_Body1.stl, Rover body_Rover_Full_Body10.stl, Rover body_Rover_Full_Body13.stl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]
2026-04-25 first pass organizing all the rover objects
    [Rover_Full_Rover_Full_Body101.stl, Rover_Full_Rover_Full_Body24.stl, Rover_Full_Rover_Full_Body27.stl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]
2026-04-25 first pieces of 3d printed kit staged for printing.
    [Lids&Side.3mf, MainBox.3mf, Rover_Full_Rover_Full_Rover body_1_Body16.stl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]
